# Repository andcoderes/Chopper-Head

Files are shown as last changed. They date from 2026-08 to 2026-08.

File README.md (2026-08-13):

# Chopper Head V2

## Acknowledgments

This firmware was strongly influenced by the [Amidala](https://github.com/thePunderWoman/Amidala) firmware by [thePunderWoman](https://github.com/thePunderWoman).

Firmware for Chopper (C1-1OP) head built on the **ESP32-WROOM-32**. Controls servo animations, RGB LED lighting effects, and communicates wirelessly with a main controller via ESP-NOW.

## Features

- **Servo animations** — Arms, periscope, and greeting motions driven by a Pololu Maestro controller over UART
- **RGB LED effects** — Jewel eyes (7-pixel each), ladder (11-pixel), center eye, and periscope lights with pulsing, bouncing, and color-change animations
- **ESP-NOW communication** — Encrypted peer-to-peer wireless protocol for low-latency remote control
- **Web interface** — Device dashboard, real-time serial monitor, and command sender
- **OTA firmware updates** — Upload new firmware over WiFi through the web interface
- **Unit tests** — Native-platform tests with mock hardware abstractions

## Hardware

| Component | Details |
|---|---|
| Microcontroller | ESP32-WROOM-32 |
| Servo controller | Pololu Maestro (UART2, GPIO 16 TX / GPIO 17 RX) |
| Left jewel eye | NeoPixel, 7 pixels, GPIO 4 |
| Right jewel eye | NeoPixel, 7 pixels, GPIO 18 |
| Center eye | NeoPixel, 1 pixel, GPIO 5 |
| Ladder | NeoPixel, 11 pixels, GPIO 19 |
| Periscope | NeoPixel, 1 pixel, GPIO 2 |

PCB design files are in the `PCB/` directory.

## Project Structure

```
src/
  main.cpp                    Entry point and main loop
  config.h                    Pin definitions, MAC addresses (keys come from secrets.h)
  lights/                     LED control (JewelEye, Ladder, PixelLight, LightController)
  servo/                      Pololu Maestro servo scripts
  communication/              ESP-NOW receiver and message types
  web/                        Embedded web server, logging, serial buffer
include/
  web_pages.h                 Auto-generated embedded HTML (built by scripts/embed_web.py)
  secrets.h                   Auto-generated ESP-NOW keys (built by scripts/load_secrets.py), gitignored
web/                          Web UI source files (HTML, CSS)
test/                         Unit tests and hardware mocks
scripts/
  embed_web.py                Pre-build script that inlines web assets into firmware
  load_secrets.py             Pre-build script: .env -> include/secrets.h
partitions/
  ota_4MB.csv                 OTA partition table
PCB/                          PCB design and CNC routing files
.env.example                  Template for ESP-NOW keys — copy to .env
```

## Prerequisites

- [Visual Studio Code](https://code.visualstudio.com/) with the [PlatformIO IDE](https://platformio.org/install/ide?install=vscode) extension
- Python 3 (used by the `embed_web.py` and `load_secrets.py` build scripts)

## Setup

1. Clone the repository and open it in VS Code.

2. Set up `.env` — see [Generating ESP-NOW keys](#generating-esp-now-keys) below. This covers `PMK_KEY`/`LMK_KEY`, `CONTROLLER_MAC`, and `WIFI_AP_PASSWORD`. The build fails with a clear error if `.env` is missing.

3. Optionally edit `src/config.h`:
   - Change `WIFI_AP_SSID` if desired.

4. Build the firmware:
   ```bash
   pio run -e esp32dev
   ```

5. Upload to the ESP32:
   ```bash
   pio run -e esp32dev -t upload
   ```

6. Open the serial monitor:
   ```bash
   pio device monitor -b 115200
   ```

## Web Interface

Connect to the **ChopperHead** WiFi access point, then open one of:

- `http://chopper.head`
- `http://chopper.local`
- `http://192.168.5.2`

### Pages

| Page | Description |
|---|---|
| Home | Device info — firmware version, MAC address, uptime, heap memory, ESP-NOW status |
| Serial Monitor | Real-time log viewer with command buttons and macro sender |
| Firmware Update | OTA upload with progress tracking |

### API

| Endpoint | Method | Description |
|---|---|---|
| `/api/info` | GET | Device telemetry (JSON) |
| `/api/monitor` | GET | Live log stream (JSON) |
| `/api/command` | POST | Send button or macro commands |

## Controls

### Button Commands (via controller or web)

| Button | Action |
|---|---|
| Y | Toggle arms in/out |
| X | Say hi (both arms) |
| B | Say hi (left arm) |
| D-pad Up | Periscope up |
| D-pad Down | Periscope down |
| D-pad Left/Right | Periscope animation |

### Macros

| Macro ID | Effect |
|---|---|
| 101 | Red eye animation |
| 103 | Periscope up sequence |
| 107 | Custom animation |

## Communication Protocol

The head communicates with the controller using packed structs over ESP-NOW:

**HeadCommand** (controller → head): button presses, macro sequences, volume, idle mode, and connection status.

**HeadTelemetry** (head → controller): connection state, animation status, and uptime. Sent every 1 second.

Connection is considered lost after 5 seconds without data.

## Running Tests

Unit tests run on the native platform (no hardware required):

```bash
pio test -e native
```

Tests cover: LightController, ServoController, ESP-NOW controller, JewelEye, PixelLight, MessageTypes, and startup animation.

## Generating ESP-NOW keys

This board talks to the other Chopper boards over encrypted ESP-NOW. Before
your first build, generate two 16-byte (128-bit) keys — a Primary Master Key
(PMK) and a Local Master Key (LMK) — and put them in a `.env` file
(gitignored, never commit it) at the project root:

```bash
cp .env.example .env
```

Generate two random 16-byte keys, each as 32 hex characters:

```bash
# Option 1: openssl
openssl rand -hex 16   # run twice — once for PMK_KEY, once for LMK_KEY

# Option 2: python
python3 -c "import secrets; print(secrets.token_hex(16))"
```

Edit `.env` and paste the values in:

```
PMK_KEY=<first random hex string>
LMK_KEY=<second random hex string>
```

**These two keys must be byte-for-byte identical across chopper body,
chopper head, and chopper receiver** — generate them once and copy the same
`.env` values into all three projects. Mismatched keys mean the boards can't
decrypt each other's ESP-NOW packets and the mesh will never connect.

`.env` also holds `CONTROLLER_MAC` — the controller's WiFi MAC address (as
hex, e.g. `C0CDD6CA29E0`), which must likewise be identical across all three
firmware projects — and `WIFI_AP_PASSWORD`, the password for this board's
local OTA-update access point (pick your own, at least 8 characters; unlike
the other values, this one doesn't need to match the other boards).

`scripts/load_secrets.py` runs automatically before every build (see
`platformio.ini`) and turns `.env` into `include/secrets.h`, which
`config.h` includes. Neither `.env` nor the generated `secrets.h` are
committed to git.

## License

All rights reserved.

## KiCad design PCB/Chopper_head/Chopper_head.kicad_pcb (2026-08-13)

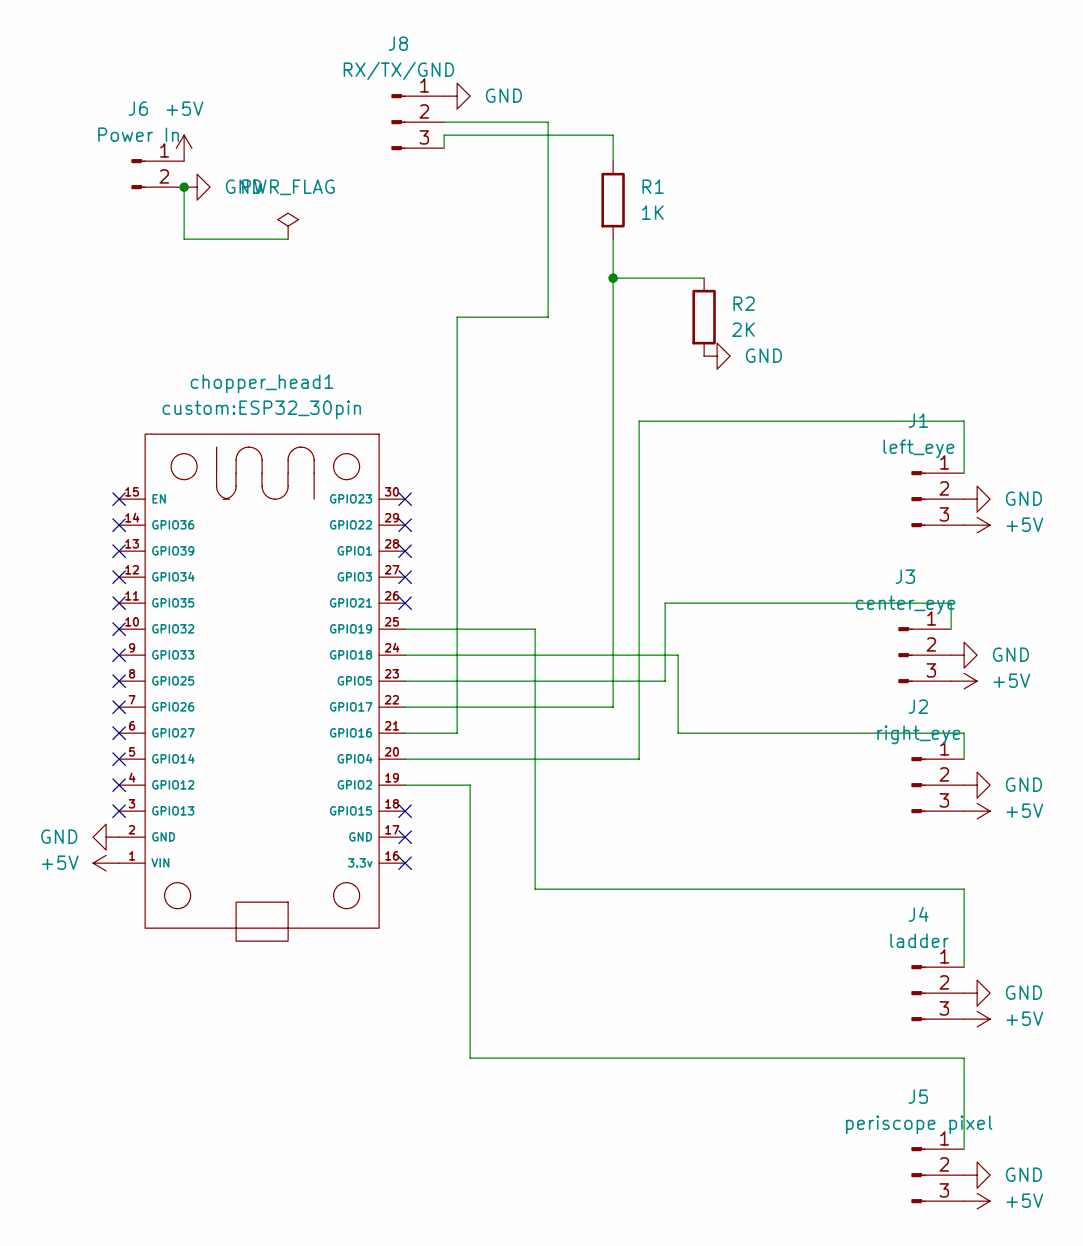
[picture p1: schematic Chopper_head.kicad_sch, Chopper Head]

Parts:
J1: left_eye; PinHeader_1x03_P2.54mm_Vertical
J2: right_eye; PinHeader_1x03_P2.54mm_Vertical
J3: center_eye; PinHeader_1x03_P2.54mm_Vertical
J4: ladder; PinHeader_1x03_P2.54mm_Vertical
J5: periscope pixel; PinHeader_1x03_P2.54mm_Vertical
J6: Power In; PinHeader_1x02_P2.54mm_Vertical
J8: RX/TX/GND; PinHeader_1x03_P2.54mm_Vertical
R1: 1K; R_Axial_DIN0204_L3.6mm_D1.6mm_P7.62mm_Horizontal
R2: 2K; R_Axial_DIN0204_L3.6mm_D1.6mm_P7.62mm_Horizontal
chopper_head1: ESP32_30pin

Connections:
+5V: J1.3, J2.3, J3.3, J4.3, J5.3, J6.1, chopper_head1.1 (VIN_1)
GND: J1.2, J2.2, J3.2, J4.2, J5.2, J6.2, J8.1, R2.2, chopper_head1.2 (GND_2), chopper_head1.17 (GND)
unnamed: J1.1, chopper_head1.20 (GPIO4_20)
unnamed: J2.1, chopper_head1.24 (GPIO18_24)
unnamed: J3.1, chopper_head1.23 (GPIO5_23)
unnamed: J4.1, chopper_head1.25 (GPIO19_25)
unnamed: J5.1, chopper_head1.19 (GPIO2_19)
unnamed: J8.2, chopper_head1.21 (GPIO16_21)
unnamed: J8.3, R1.1
unnamed: R1.2, R2.1, chopper_head1.22 (GPIO17_22)

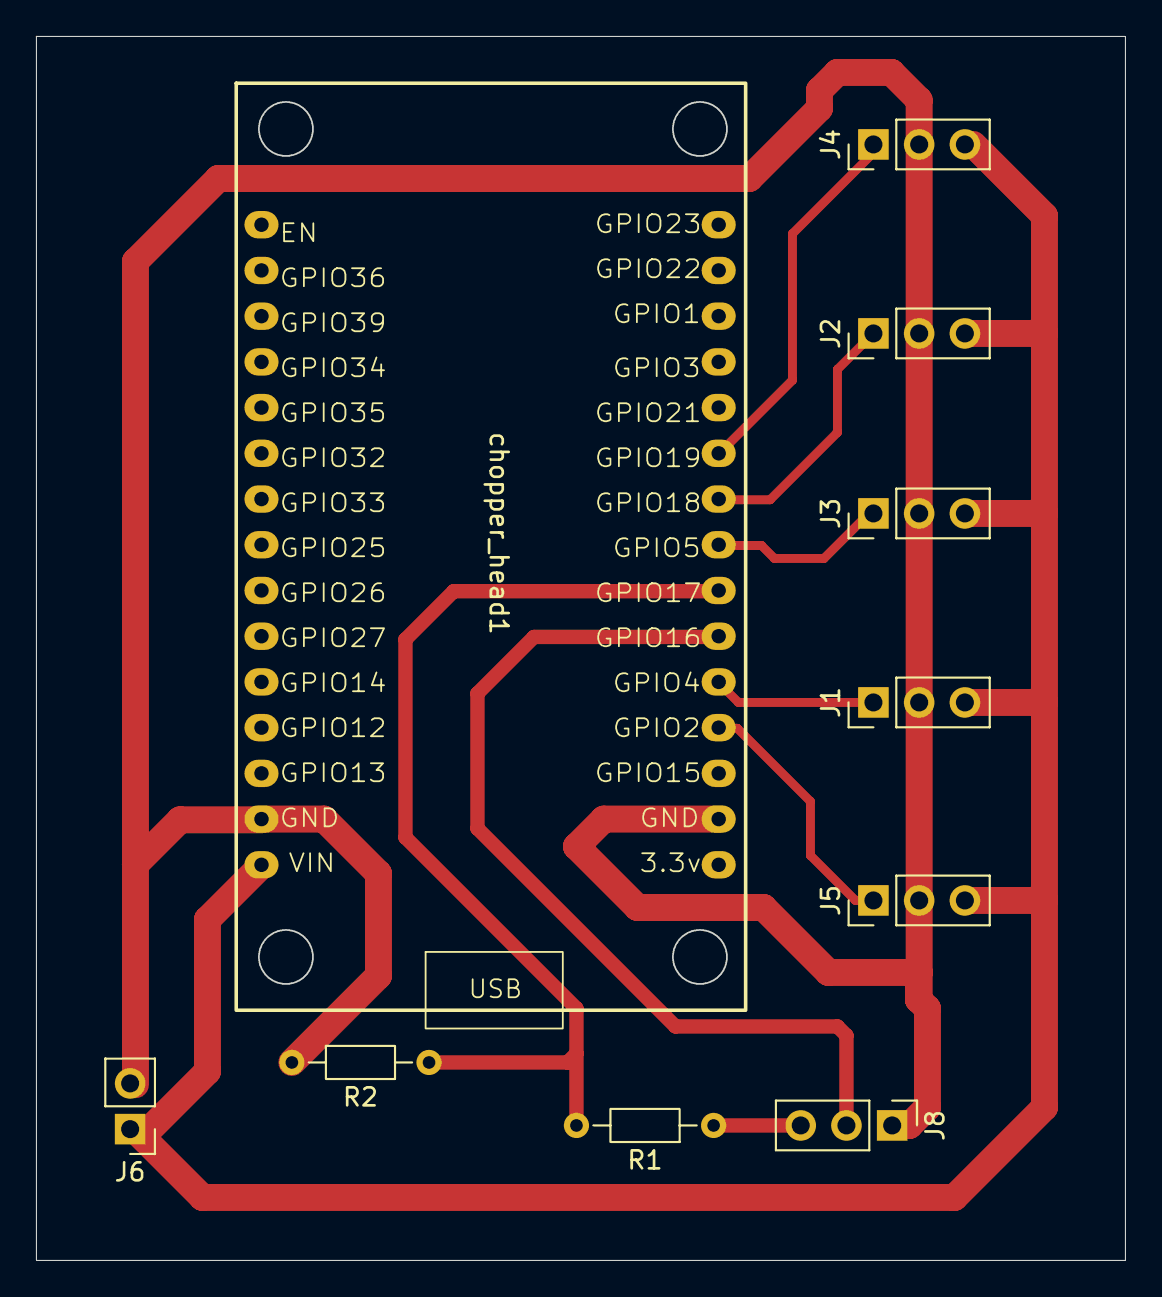
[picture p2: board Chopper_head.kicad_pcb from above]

Board: 2 copper layers, 60.5 x 68.0 mm, 10 parts (0 on the bottom side), 10 nets.

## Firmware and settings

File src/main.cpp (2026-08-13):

#ifndef UNIT_TEST

#include <Arduino.h>
#include <WiFi.h>
#include <esp_wifi.h>
#include "config.h"
#include "communication/EspNowController.h"
#include "communication/MessageTypes.h"
#include "servo/ServoController.h"
#include "lights/LightController.h"
#include "web/WebController.h"
#include "web/monitor_buf.h"
#include "web/logger.h"

EspNowController espNow;
ServoController servo;
LightController lights;
WebController webController;

void logCommand(const HeadCommand& cmd) {
    if (cmd.button[0] != '\0') {
        logAll("CMD: btn=%s", cmd.button);
    } else if (cmd.macro[0] != 0) {
        logAll("CMD: macro=%d,%d,%d,%d",
               cmd.macro[0], cmd.macro[1], cmd.macro[2], cmd.macro[3]);
    } else {
        logAll("CMD: status=%d", cmd.status);
    }
}

void onCommand(const HeadCommand& cmd) {
    logCommand(cmd);

    switch (cmd.status) {
        case STATUS_BUTTONS:
            servo.animate(cmd.button, cmd.macro, 4);
            lights.animate(cmd.button, cmd.macro, 4);
            break;

        case STATUS_DEBUG:
            servo.animate(cmd.button, cmd.macro, 4);
            lights.animate(cmd.button, cmd.macro, 4);
            break;

        case STATUS_CONNECTION:
            lights.setConnectionStatus(cmd.connectionStatus == 1);
            break;

        default:
            break;
    }
}

void setup() {
    Serial.begin(115200);
    delay(500);

    servo.setup();
    lights.setup();

    // WiFi: AP+STA mode for ESP-NOW + web server coexistence
    WiFi.mode(WIFI_AP_STA);
    WiFi.softAP(WIFI_AP_SSID, WIFI_AP_PASSWORD);
    WiFi.softAPConfig(IPAddress(192,168,5,1), IPAddress(192,168,5,1), IPAddress(255,255,255,0));
    esp_wifi_set_ps(WIFI_PS_NONE);

    espNow.setup();
    espNow.setCommandCallback(onCommand);

    webController.setup();
    webController.setCommandCallback(onCommand);

    logAll("Chopper V2 Head ready");
    logAll("AP IP: %s", WiFi.softAPIP().toString().c_str());
}

void loop() {
    if (!servo.isReady()) {
        servo.checkConnection();
    }
    lights.setMaestroReady(servo.isReady());

    // Sync from the ESP-NOW liveness timeout *before* dispatching any
    // command this tick, so an explicit STATUS_CONNECTION signal handled
    // during espNow.loop() below is the last word for this iteration,
    // not immediately clobbered by this stale-from-last-tick check.
    lights.setConnectionStatus(espNow.isConnected());

    espNow.loop();
    webController.loop(servo.isHandshakePending());
    lights.standBy();
}

#endif // UNIT_TEST

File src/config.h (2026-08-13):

#pragma once
#include <Arduino.h>

// --- Pin assignments (ESP32 WROOM-32) ---
#define PIN_MAESTRO_TX      16   // UART2 TX -> Pololu Maestro
#define PIN_MAESTRO_RX      17   // UART2 RX (reserved)
#define PIN_LEFT_EYE_JEWEL  4    // NeoPixel data, 7 pixels
#define PIN_RIGHT_EYE_JEWEL 18   // NeoPixel data, 7 pixels
#define PIN_CENTER_EYE      5    // NeoPixel data, 1 pixel
#define PIN_LADDER          19   // NeoPixel data, 11 pixels
#define PIN_PERISCOPE       2    // NeoPixel data, 1 pixel

#define NUM_JEWEL_PIXELS    7
#define NUM_SINGLE_PIXEL    1
#define NUM_LADDER_PIXELS   11

// --- Secrets (ESP-NOW keys, controller MAC, WiFi AP password) ---
#ifdef UNIT_TEST
// Dummy values for native unit tests — no real ESP-NOW traffic or AP off-device.
static const uint8_t PMK_KEY[16] = {0};
static const uint8_t LMK_KEY[16] = {0};
static const uint8_t CONTROLLER_MAC[6] = {0};
#define WIFI_AP_PASSWORD "test"
#else
#include "secrets.h"  // defines PMK_KEY, LMK_KEY, CONTROLLER_MAC, WIFI_AP_PASSWORD — generated from .env, see README
#endif

// --- Timing constants ---
#define HEARTBEAT_INTERVAL_MS   1000   // How often to send telemetry
#define CONNECTION_TIMEOUT_MS   5000   // No data = disconnected

// --- WiFi AP for web server ---
#define WIFI_AP_SSID     "ChopperHead"
// WIFI_AP_PASSWORD comes from secrets.h (generated from .env, see README)

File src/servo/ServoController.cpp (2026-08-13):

#include "ServoController.h"
#include "../web/logger.h"

void ServoController::setup() {
    Serial2.begin(9600, SERIAL_8N1, PIN_MAESTRO_RX, PIN_MAESTRO_TX);
    delay(500);
}

bool ServoController::isReady() const {
    return ready_;
}

bool ServoController::checkConnection() {
    if (ready_) return true;

    if (!checkPending_) {
        // Flush any stale data
        while (Serial2.available()) Serial2.read();
        // Send getErrors compact protocol command
        logAll("Maestro: trying to connect...");
        Serial2.write(0xA1);
        checkPending_ = true;
        checkSentTime_ = millis();
        return false;
    }

    // Waiting for response
    if (Serial2.available() >= 2) {
        Serial2.read();
        Serial2.read();
        ready_ = true;
        checkPending_ = false;
        logAll("Maestro: connected");
        return true;
    }

    // Timeout after 100ms — retry next loop
    if (millis() - checkSentTime_ >= 100) {
        checkPending_ = false;
    }

    return false;
}

void ServoController::stop() {
    maestro_.stopScript();
}

void ServoController::animate(const char* button, const int16_t macros[], int macroCount) {
    // Try button first
    if (button[0] != '\0') {
        logAll("Servo: btn=%s", button);
        playScriptButton(String(button));
        return;
    }

    // Try macros - build a key string from the macro values
    String macrosString = "";
    for (int i = 0; i < macroCount && macros[i] != 0; i++) {
        macrosString += String(macros[i]);
    }

    if (macrosString != "") {
        logAll("Servo: macro=%s", macrosString.c_str());
        playScriptButton(macrosString);
    }
}

void ServoController::playScriptButton(const String& keysAction) {
    int actionIndex = -1;
    for (int i = 0; i < NUM_KEYS; i++) {
        if (arrayKeys_[i] == keysAction) {
            actionIndex = i;
            break;
        }
    }

    if (actionIndex != -1) {
        int currentIndex = currentIndex_[actionIndex];
        int scriptToRun = scripts_[actionIndex][currentIndex];
        currentIndex = (currentIndex + 1) % 2;
        currentIndex_[actionIndex] = currentIndex;

        if (checkAnimation(scriptToRun)) {
            logAll("Servo: restart script %d", scriptToRun);
            maestro_.restartScript(scriptToRun);
        }
    }
}

void ServoController::execute(int scriptToRun) {
    if (checkAnimation(scriptToRun)) {
        maestro_.restartScript(scriptToRun);
    }
}

bool ServoController::checkAnimation(int animation) {
    if (animation == outHandAnimation_) {
        outComponent_[0] = true;
        return true;
    }
    if (outComponent_[0]) {
        if (animation == inHandAnimation_) {
            outComponent_[0] = false;
            return true;
        }
        for (int x = 0; x < 3; x++) {
            if (animationRequiredHandOut_[x] == animation) {
                return true;
            }
        }
    }
    if (animation > 3) {
        return true;
    }
    return false;
}

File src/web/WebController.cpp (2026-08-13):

#ifndef UNIT_TEST

#define MONITOR_BUF_OWNER
#include "WebController.h"
#include "logger.h"
#include "web_pages.h"
#include <Update.h>
#include <WiFi.h>
#include <ESPmDNS.h>

#ifndef FIRMWARE_VERSION
#define FIRMWARE_VERSION "0.0.0"
#endif

void WebController::setup() {
    monDrainInit(drainSerial_,  "LOG: ", 'i');
    monDrainInit(drainSerial2_, "S2: ",  'r');

    server_.on("/",        HTTP_GET,  [this]() { handleHome(); });
    server_.on("/monitor", HTTP_GET,  [this]() { handleMonitor(); });
    server_.on("/api/monitor", HTTP_GET, [this]() { handleMonitorApi(); });
    server_.on("/update",  HTTP_GET,  [this]() { handleUpdate(); });
    server_.on("/update",  HTTP_POST,
        [this]() { handleUpdateUpload(); },
        [this]() {
            HTTPUpload& upload = server_.upload();
            if (upload.status == UPLOAD_FILE_START) {
                updateSuccess_ = false;
                if (!Update.begin(UPDATE_SIZE_UNKNOWN)) {
                    Update.printError(Serial);
                }
            } else if (upload.status == UPLOAD_FILE_WRITE) {
                if (Update.write(upload.buf, upload.currentSize) != upload.currentSize) {
                    Update.printError(Serial);
                }
            } else if (upload.status == UPLOAD_FILE_END) {
                if (Update.end(true)) {
                    updateSuccess_ = true;
                    logAll("OTA update success, rebooting...");
                } else {
                    Update.printError(Serial);
                }
            }
        }
    );
    server_.on("/api/command", HTTP_POST, [this]() { handleCommandApi(); });
    server_.on("/api/info", HTTP_GET, [this]() { handleInfoApi(); });

    // DNS: resolve all queries to the AP IP so "chopper.head" (or any URL) works
    dns_.start(53, "*", WiFi.softAPIP());

    // mDNS: advertise "chopper.local" for devices that support it
    if (MDNS.begin("chopper")) {
        MDNS.addService("http", "tcp", 80);
    }

    server_.begin();
    logAll("Web server started on http://chopper.head");
}

void WebController::loop(bool suppressSerial2Drain) {
    dns_.processNextRequest();
    server_.handleClient();

    // Drain Serial (USB console) into monitor buffer
    uint32_t now = millis();
    monDrainSeedLabel(drainSerial_);
    while (Serial.available()) {
        monDrainByte(drainSerial_, Serial.read(), now);
    }
    monDrainSilenceCheck(drainSerial_, now);

    // Drain Serial2 (Maestro UART) into monitor buffer — unless a
    // ServoController handshake is pending, in which case leave the bytes
    // alone so checkConnection() can see its 2-byte reply intact.
    if (!suppressSerial2Drain) {
        monDrainSeedLabel(drainSerial2_);
        while (Serial2.available()) {
            monDrainByte(drainSerial2_, Serial2.read(), now);
        }
        monDrainSilenceCheck(drainSerial2_, now);
    }
}

void WebController::handleHome() {
    server_.send(200, "text/html", WEB_PAGE_HOME);
}

void WebController::handleMonitor() {
    server_.send(200, "text/html", WEB_PAGE_MONITOR);
}

void WebController::handleMonitorApi() {
    String json;
    json.reserve(MON_LINES * (MON_LINE_LEN + 24));
    json += "{\"seq\":";
    json += sMonSeq;
    json += ",\"lines\":[";

    uint16_t count = sMonCount;
    uint16_t start = (sMonHead + MON_LINES - count) % MON_LINES;
    for (uint16_t i = 0; i < count; i++) {
        uint16_t idx = (start + i) % MON_LINES;
        if (i > 0) json += ',';
        json += "{\"t\":\"";
        monJsonAppendEscaped(json, sMonBuf[idx].text);
        json += "\",\"c\":\"";
        switch (sMonBuf[idx].cls) {
            case 't': json += "tx"; break;
            case 'r': json += "rx"; break;
            default:  json += "info"; break;
        }
        json += "\"}";
    }
    json += "]}";
    server_.send(200, "application/json", json);
}

void WebController::handleCommandApi() {
    if (!commandCallback_) {
        server_.send(500, "text/plain", "No command handler");
        return;
    }

    String button = server_.arg("button");
    String macro  = server_.arg("macro");

    HeadCommand cmd = {};
    cmd.msgType = 1;
    cmd.status  = STATUS_BUTTONS;
    cmd.connectionStatus = 1;

    if (button.length() > 0) {
        strncpy(cmd.button, button.c_str(), sizeof(cmd.button) - 1);
    }

    if (macro.length() > 0) {
        // Parse comma-separated macro values (e.g. "101,103")
        int idx = 0;
        int start = 0;
        for (int i = 0; i <= (int)macro.length() && idx < 4; i++) {
            if (i == (int)macro.length() || macro[i] == ',') {
                if (i > start) {
                    cmd.macro[idx++] = (int16_t)macro.substring(start, i).toInt();
                }
                start = i + 1;
            }
        }
    }

    // Log to monitor
    String logMsg = "WEB> ";
    if (button.length() > 0) {
        logMsg += "btn=" + button;
    }
    if (macro.length() > 0) {
        if (button.length() > 0) logMsg += " ";
        logMsg += "macro=" + macro;
    }
    monAppend(logMsg.c_str(), 't');

    commandCallback_(cmd);
    server_.send(200, "text/plain", "OK");
}

void WebController::handleUpdate() {
    server_.send(200, "text/html", WEB_PAGE_UPDATE);
}

void WebController::handleUpdateUpload() {
    server_.send(200, "text/plain", updateSuccess_ ? "OK" : "FAIL");
    if (updateSuccess_) {
        delay(500);
        ESP.restart();
    }
}

void WebController::handleInfoApi() {
    String json;
    json.reserve(256);
    json += "{\"version\":\"";
    json += FIRMWARE_VERSION;
    json += "\",\"uptime\":";
    json += millis();
    json += ",\"heap\":";
    json += ESP.getFreeHeap();
    json += ",\"mac\":\"";
    json += WiFi.macAddress();
    json += "\",\"espnow\":true}";
    server_.send(200, "application/json", json);
}

#endif // UNIT_TEST
